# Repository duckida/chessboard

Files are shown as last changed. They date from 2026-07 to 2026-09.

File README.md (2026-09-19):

Screenshot 2026-09-19 at 4 45 12 PM

## what is this?


An electronic chessboard to play against others online, chess engines, or others in person (and get hints)!

Click [here](https://user-cdn.hackclub-assets.com/019f8627-e8d6-7e0b-9ccc-8cd9828df5a0/chessboard%20demo.mp4) for a video demo!

## why did I build it?
I love playing chess, and one of the best ways to improve is with practice against others or a computer. However, this normally requires playing online, which is more distracting. I wanted to build a chessboard where I could play with anyone in the world or with a computer on a traditional board.

## how it works
The chessboard is controlled by a Raspberry Pi (Zero 2 W), which runs the backend API, LEDs, main hardware loop & displays the frontend. 

Reed switches are read by a Raspberry Pi Pico and data is transmitted to the main Pi over UART.

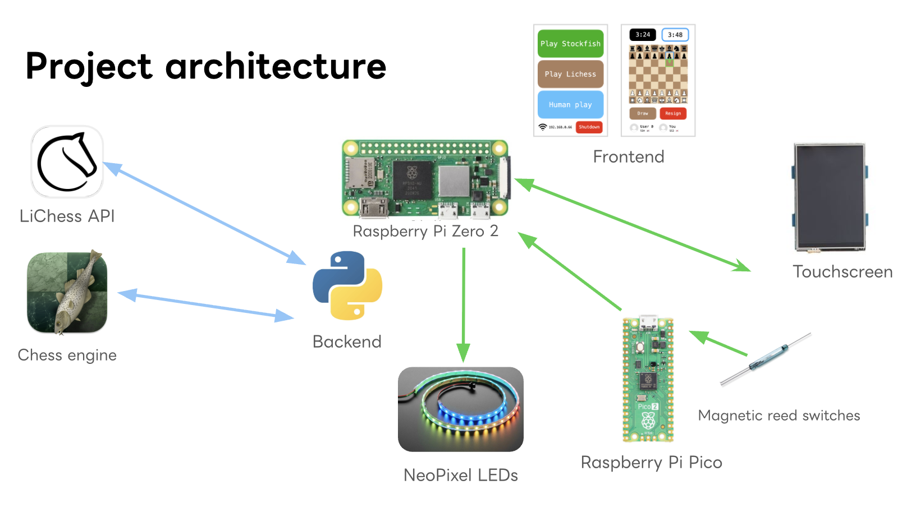
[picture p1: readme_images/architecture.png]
Architecture diagram


## how to set up
Follow the instructions in each folder (backend, frontend, cad and pico_matrix_scan)'s README to deploy each module!

So far, only playing against the chess engine works, with more features coming soon!

A bill of materials can be found in BOM.csv.

## my build journey


Throughout the project, I kept a journal at [JOURNAL.md](https://github.com/duckida/chessboard/blob/main/JOURNAL.md)!

AI usage is also declared in JOURNAL.md.

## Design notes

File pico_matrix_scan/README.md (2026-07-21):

# pico-matrix-scan

This folder contains the code to flash onto a Pico connected to the reed switches.

It reads the matrix of reed switches and outputs to the Pi over Serial (USB).

You only need to copy `main.py` and `keypad_lib.py`.

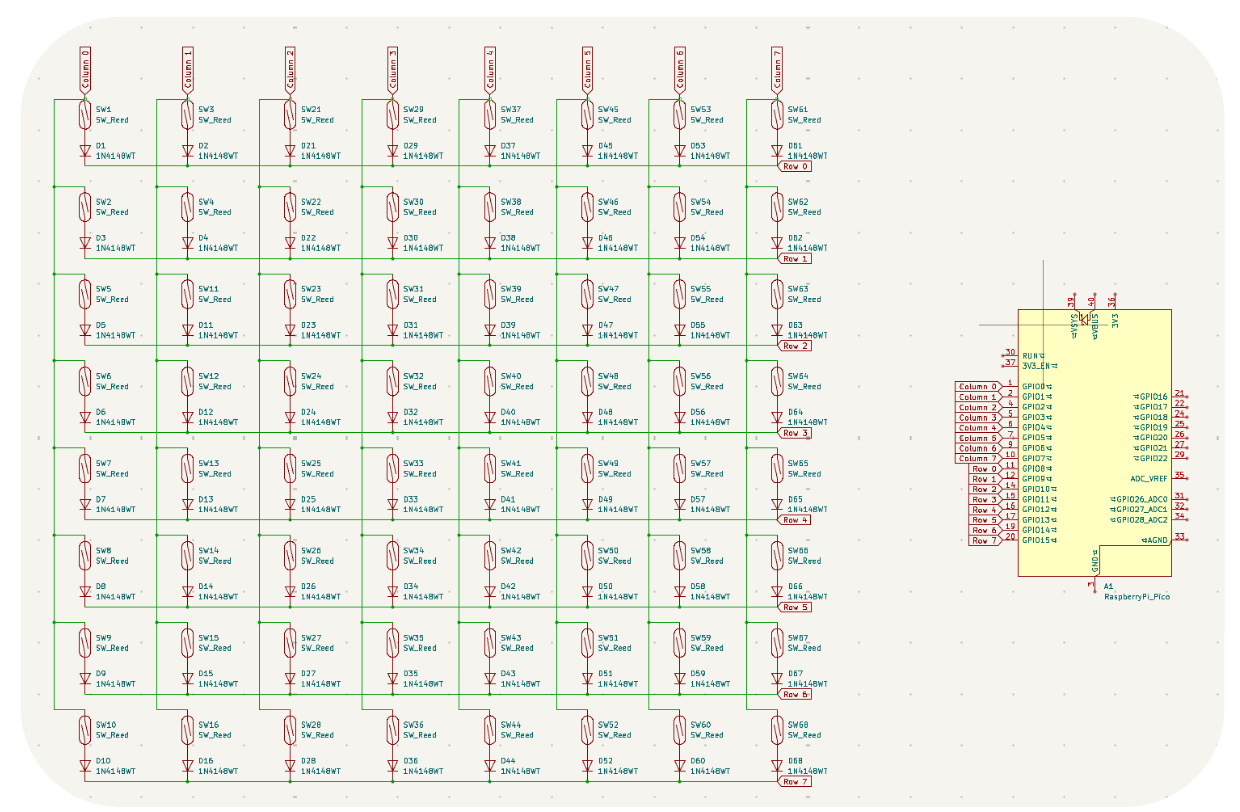
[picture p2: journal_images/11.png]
Full KiCAD schematic


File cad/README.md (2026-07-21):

# cad

This folder contains the CAD designs for the chessboard.

You will need to 3D print all the items in `3d-prints/` - the board has been split into parts so it fits on print beds. 

You will also need to laser cut the base and spacer from `laser-cut/`.

The chessboard was designed in TinkerCAD but has been exported to Fusion 360 .f3d for editing if required.

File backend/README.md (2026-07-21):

# backend

This is the folder that runs on the Raspberry Pi inside the chessboard, communicating with LiChess & the Stockfish chess engine. It also scans hardware inputs and manages the NeoPixel LEDs.

## backend API
The API routes that create and modify games and connect to different services are in `app.py`, which is a Flask API. 

Details about API routes can be found in [API.md](https://github.com/duckida/chessboard/blob/main/backend/API.md).

## hardware interface
The backend folder also contains 2 hardware modules, `leds.py` which exposes a simple control interface for WS2812B strips used in the chessboard (this needs root) and `matrix.py` which reads the matrix over UART serial.

## backend deployment instructions
1. Install uv: `curl -LsSf https://astral.sh/uv/install.sh | sh` and restart your shell
2. Clone this repo and enter: `git clone https://github.com/duckida/chessboard && cd chessboard`
3. Enter the backend and install packages: `cd backend && uv sync`
4. Download Stockfish 14 and compile it, and put this compiled binary at `/home/pi/chessboard/stockfish`
5. Get a LiChess API token and put it in `.env` (example: `LICHESS_TOKEN="lip..."
`)
4. In one terminal tab, run the backend API: `uv run app.py`
5. In another tab, run the hardware scanner / main loop: `sudo -E $(which uv) run main.py` (sudo is needed for LED interfacing and serial reading)

### systemd service - API
1. `sudo systemctl edit --full api.service --force`
2. Paste this in:
```
[Unit]
Description=Chessboard API Service
After=network.target

[Service]
Type=simple
User=pi
WorkingDirectory=/home/pi/chessboard/backend
ExecStart=/home/pi/.local/bin/uv run /home/pi/chessboard/backend/app.py

[Install]
WantedBy=network.target
```
3. `sudo systemctl daemon-reload`
4. `sudo systemctl enable api.service`
5. Reboot the Pi: `sudo reboot`

### systemd service - main hardware loop
> This runs as root, run at your own risk!

1. `sudo systemctl edit --full main.service --force`
2. Paste this in:
```
[Unit]
Description=Chessboard main loop Service
After=network.target api.service 
Wants=api.service

[Service]
Type=simple
User=root
WorkingDirectory=/home/pi/chessboard/backend
ExecStart=/home/pi/.local/bin/uv run /home/pi/chessboard/backend/main.py
Restart=on-failure
RestartSec=3

[Install]
WantedBy=network.target
```
3. `sudo systemctl daemon-reload`
4. `sudo systemctl enable main.service`
5. Reboot the Pi: `sudo reboot`

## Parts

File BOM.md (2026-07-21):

| Component | Link | Quantity |
| --- | --- | --- |
| Raspberry Pi | [Raspberry Pi](https://www.raspberrypi.com/products/raspberry-pi-zero-2-w/) | 1 |
| 16GB microSD card | [CPC](https://cpc.farnell.com/integral/inmsdh16g-100v10/16gb-microsdhc-v10-uhs-i-u1/dp/MD01157) | 1 |
| NeoPixel strip (30 / m) | [Amazon](https://www.amazon.co.uk/BTF-LIGHTING-Individual-Addressable-60Pixels-Non-Waterproof/dp/B088BB8WTZ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) | 3 meters |
| Reed switches | [Amazon](https://www.amazon.co.uk/QitinDasen-MKA-14103-Magnetic-Induction-Normally/dp/B07ZD4JF76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) | 64 |
| RPi Pico | [Raspberry Pi](https://www.raspberrypi.com/products/raspberry-pi-pico/) | 1 |
| Protoboard |  | 265x265mm |
| Diodes | [Amazon](https://www.amazon.co.uk/100PCS-1N4148-IN4148-High-Speed-Switch/dp/B07YZ8G7TG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) | 64 |
| Touchscreen | [Micro Center](https://www.microcenter.com/product/632693/inland-35-inch-tft-lcd-touch-screen-monitor) | 1 |
| Magnetic chess pieces | [Amazon](https://www.amazon.co.uk/gp/product/B086632FYP/ref=ox_sc_act_title_2?smid=A1SD225FBQ4KA&psc=1) | 1 set |

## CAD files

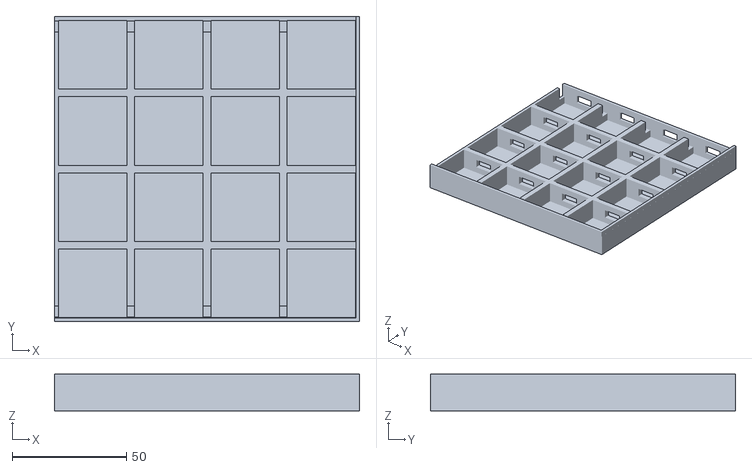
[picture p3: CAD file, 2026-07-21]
cad/3d-prints/chessboard-c.stl
133.2 x 133.2 x 16.0

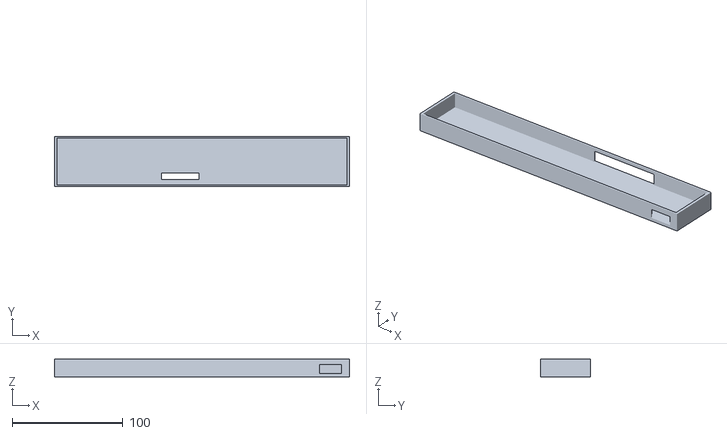
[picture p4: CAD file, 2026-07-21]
cad/3d-prints/chessboard-e.stl
266.4 x 45.0 x 16.0

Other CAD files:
cad/3d-prints/chessboard-a.stl
cad/3d-prints/chessboard-b.stl
cad/3d-prints/chessboard-d.stl
cad/Chessboard.f3d

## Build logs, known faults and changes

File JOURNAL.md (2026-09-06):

# chessboard journal

June 23: Spent 20mins creating a project brief and bill of materials

June 27: Spend 45mins writing a Python program to use `berserk` API to connect to LiChess and learn about the streamed events

July 2: looked for parts online from a variety of resellers

July 4: 
- ordered parts on Amazon
- used threading to make a basic Flask API to search for games
- added make move function
 
July 5: 
- got a basic API working and was able to move pieces against another player with it! 
- Learned the basics of Next.js and started making the frontend

July 6: got basic interaction between the frontend & backend working!

July 7: 
- parts arrived! 
- got a basic code with reed switches to work. 
- Designed a prototype for 4 chessboard squares in TinkerCAD.

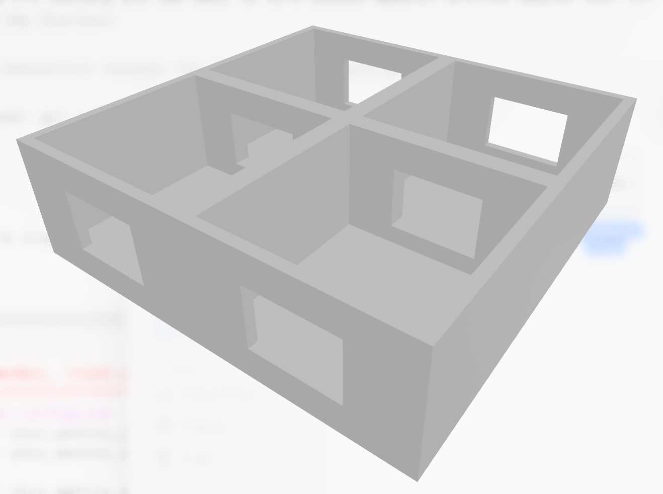
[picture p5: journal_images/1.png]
First TinkerCAD design


- Next, I tested my NeoPixels, and I need to find a way to diffuse them better.

- This design wasn't as good for the reed switch height, so I did another one which was less tall and thinner surface, and tested with 2 squares.

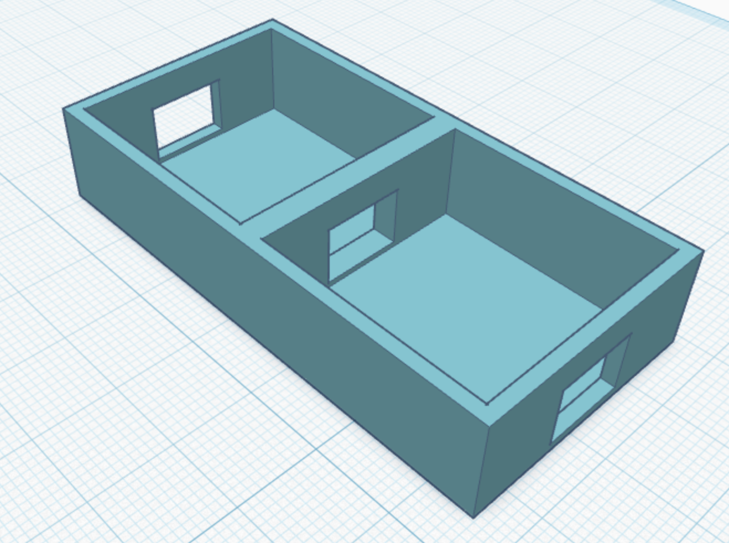
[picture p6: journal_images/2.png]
Improved design


- This also lights up better, and fits the reed switch!

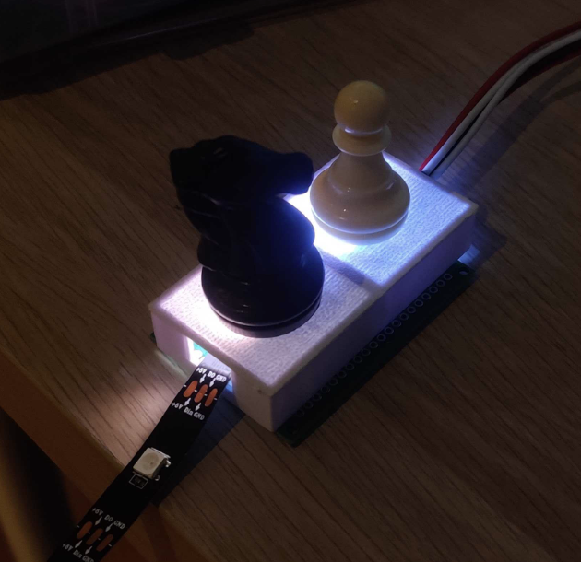
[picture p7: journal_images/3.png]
Printed improved design


July 8: 
- 3D printed a 4-square version of the new design. 
- Drew up a KiCad schematic of the matrix layout!

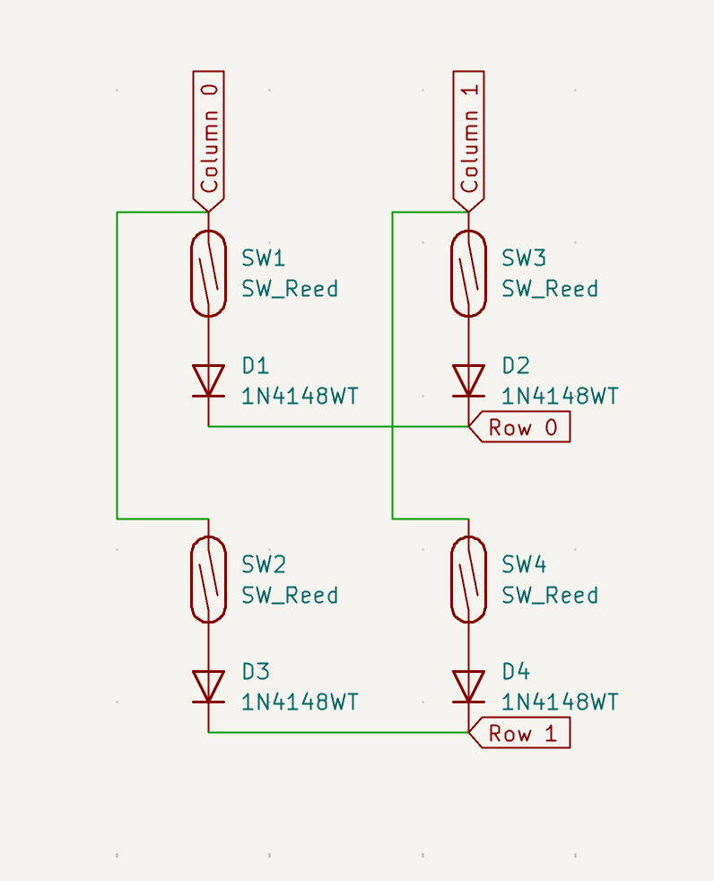
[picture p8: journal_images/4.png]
Matrix schematic


- Soldered the reed switches in a matrix layout
- Got the 2x2 mini board to work!
- Wrote a custom matrix keypad library based on an existing one to output an array which i can use

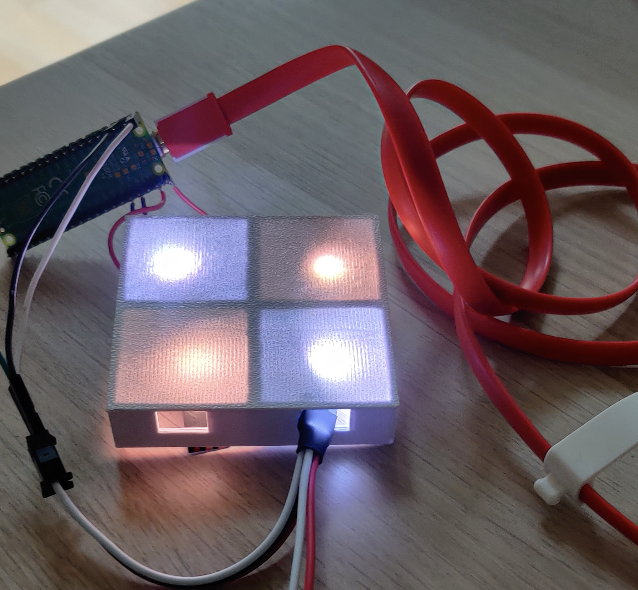
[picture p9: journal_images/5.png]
Working 2x2 mini board


July 9 - Created a home page with Next.js (learned about Tailwind CSS and shadcn/ui)

July 10:
- Fixed a duplicate move issue in the frontend
- Soldered pins to my Raspberry Pi (decided to use a Zero 2W as it's smaller)
- Flashed the SD card for the Pi and configured the OS
- Compiled Stockfish on the Pi
- Got Stockfish best move analysis to show on the frontend!

July 12: Set up the Pi touchscreen & X11

July 13:
- Designed a full-size chessboard in TinkerCAD and added a section for the Pi, screen & Pico (had to split it into multiple pieces to print)
- Printed the end section which stores the Pi, Pico and screen
- Worked on the backend, creating a class for Stockfish game and API routes for it

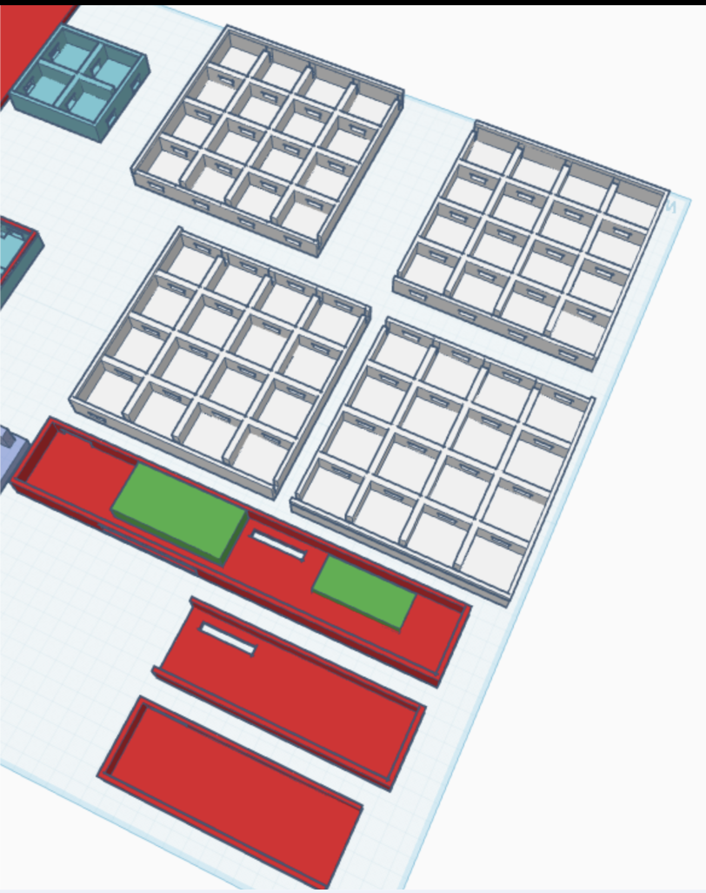
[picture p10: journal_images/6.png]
TinkerCAD design


July 14:
- Printed the chessboard squares
- Soldered the display pins (messed this up so had to redo it) and NeoPixel strip to the Pi
- Tested the NeoPixel strip with the Pi
- Lots of debugging to get the screen to work (messed up pins, framebuffers, and bridging!)
- Software work - added human vs human game routes to the API and integrated them into the frontend
- Compiled the Next.js app
- Designed a KiCAD schematic for the full size matrix

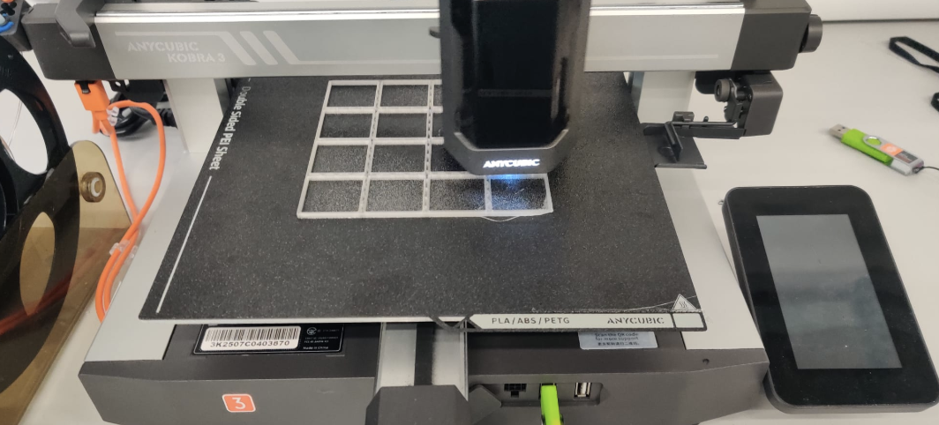
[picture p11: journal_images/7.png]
Printing squares

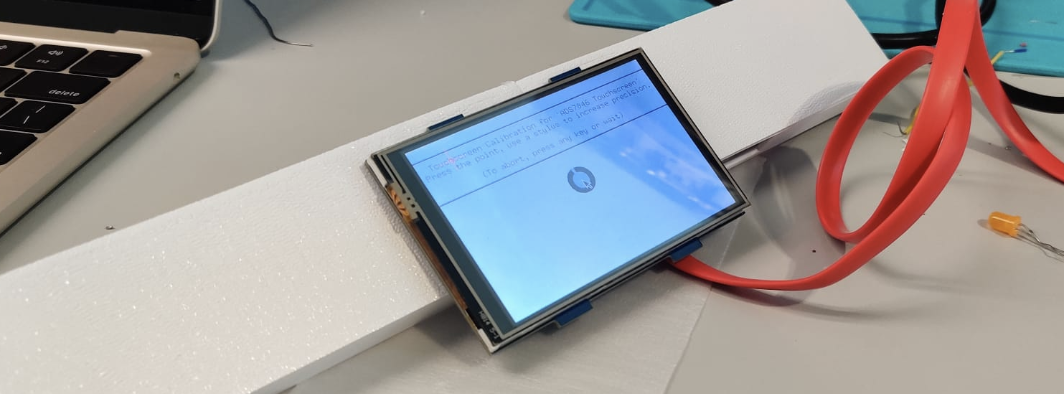
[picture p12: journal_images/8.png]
Display working

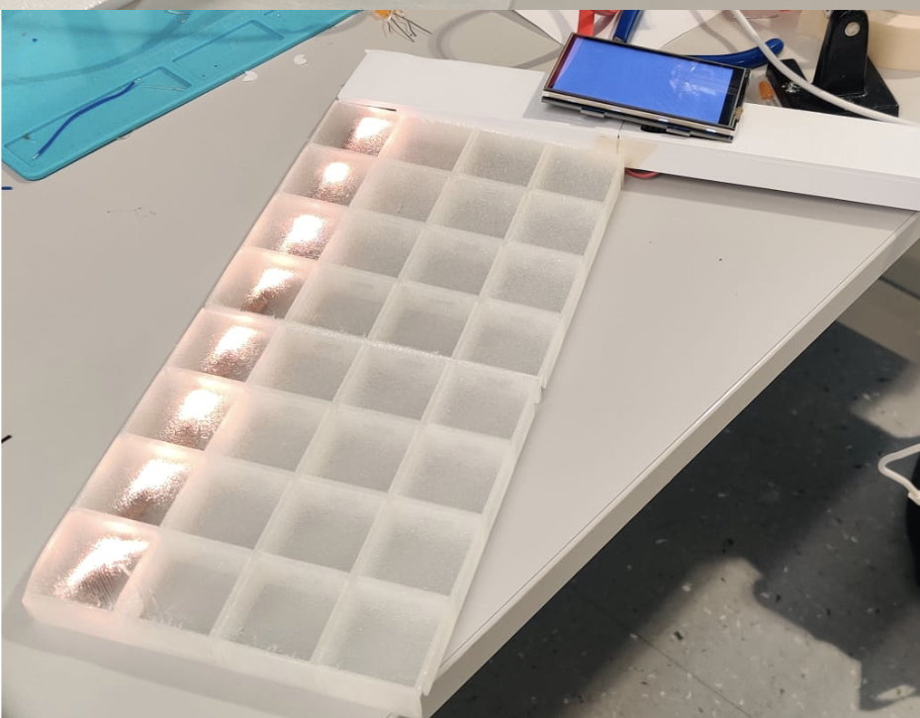
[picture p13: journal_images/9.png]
Tested NeoPixel strip


July 15:
- Used a guillotine to cut the protoboards to size
- Soldered the reed switches to the protoboard
- Soldered wires for the matrix columns

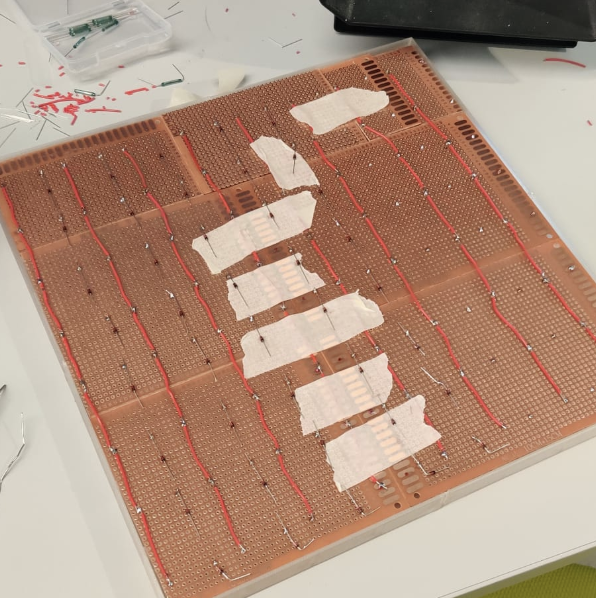
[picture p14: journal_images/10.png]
All the NeoPixels fitting in the board


July 16:
- Soldered all diodes to the matrix
- Soldered row wires
- Added the Pico pinout of rows & columns to my KiCAD schematic
- Soldered the column & rows to the Pico 
- Tested the matrix, many squares didn't work so I had to resolder loose wires etc.

Full KiCAD schematic
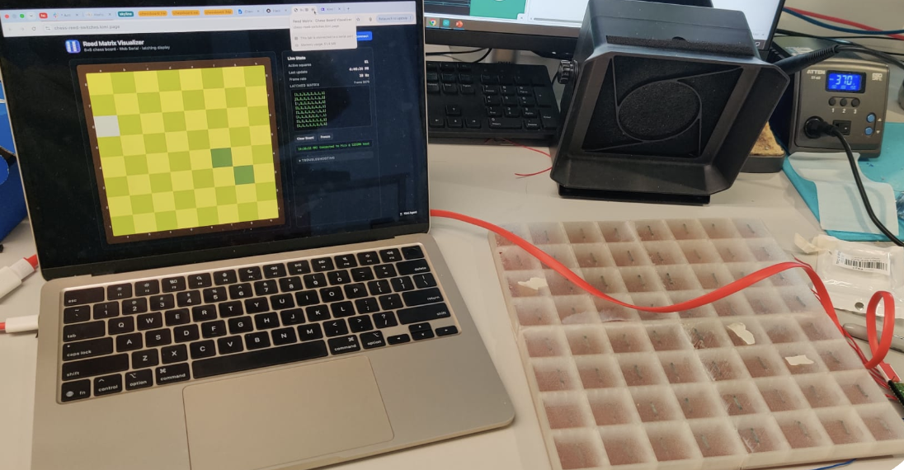
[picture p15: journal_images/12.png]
Testing the reed switches with a vibe-coded webapp


July 17:
- Got all the matrix keys to work after much testing, resoldering and alignment!
- Laser cut a base and base spacer
- Tried to put the NeoPixels in and failed, so made the holes bigger
- Soldered the NeoPixels and put them in through the reed switches
- Started testing the NeoPixels

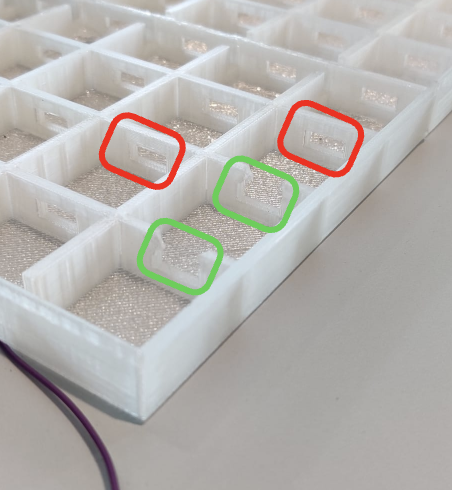
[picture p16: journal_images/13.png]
Holes I had to cut

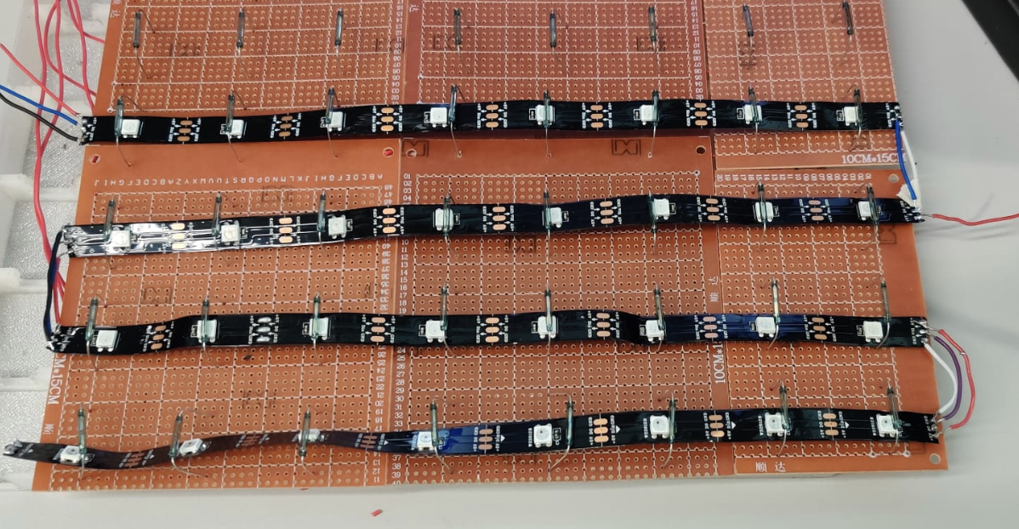
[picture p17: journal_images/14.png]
Soldering NeoPixels


July 18: soldered & fixed some NeoPixels that didn't work

July 19:
- Got all the NeoPixels to work!
- Deployed the frontend to Vercel and ran it `DISPLAY=:0 surf -F https://chessboard-moa.vercel.app/`

July 20:
- Got all the reed switches and NeoPixels to work
- Hot glued the protoboards to the 3D printed chessboard
- Hot glued the screen enclosure to this
- Soldered Pico UART to the Pi
- Wrote READMEs for the frontend & backend
- Put a paper diffuser layer on the top

All the parts in the shell
Top with the diffuser layer

July 21:
- Wrote a basic demo code to play against Stockfish
- Switched to Stockfish 14 to minimize resource use
- Updated the LED matrix to square mapping
- Got up and down events to work with the reed switches
- Wrote README for the project and backend

Then - Sep 6:
- Used AI to create a main.py (i aim to rewrite this by hand after creating the unified API) that links the physical board with the backend
- Added undo API route to Stockfish and an undo button to the UI
- Cleaned up the UI and got it to fit on the screen
- Got the human-vs-human mode to work, and added hint & undo modes
- Added player information route and UI to the LiChess screen
- Started work on a unified API to make interfacing easier between modes

### AI usage
AI helped me with:
- understanding the LiChess API and its responses
- choosing parts to order (comparing datasheets)
- learning Next.js
- help me setup the Pi desktop and framebuffer
- Exporting the Next.js site as static HTML
- Creating a UI to test reed switches (not shipped in the final code)
- Using UART hardware Serial on the Pico and reading this on the Pi
- Fixing systemd service order
- General debugging
- The current `main.py` is written by AI, but this is after shipping to Hack Club. I aim to rewrite this completely myself in the future.

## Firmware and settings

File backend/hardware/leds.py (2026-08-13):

from rpi_ws281x import PixelStrip, Color, ws
import time

class LEDStrip:
    PIXEL_SQUARE_MAPPING = {
        "a1": 56, "a2": 55, "a3": 40, "a4": 39, "a5": 24, "a6": 23, "a7": 8,  "a8": 7,
        "b1": 57, "b2": 54, "b3": 41, "b4": 38, "b5": 25, "b6": 22, "b7": 9,  "b8": 6,
        "c1": 58, "c2": 53, "c3": 42, "c4": 37, "c5": 26, "c6": 21, "c7": 10, "c8": 5,
        "d1": 59, "d2": 52, "d3": 43, "d4": 36, "d5": 27, "d6": 20, "d7": 11, "d8": 4,
        "e1": 60, "e2": 51, "e3": 44, "e4": 35, "e5": 28, "e6": 19, "e7": 12, "e8": 3,
        "f1": 61, "f2": 50, "f3": 45, "f4": 34, "f5": 29, "f6": 18, "f7": 13, "f8": 2,
        "g1": 62, "g2": 49, "g3": 46, "g4": 33, "g5": 30, "g6": 17, "g7": 14, "g8": 1,
        "h1": 63, "h2": 48, "h3": 47, "h4": 32, "h5": 31, "h6": 16, "h7": 15, "h8": 0,
    }

    LED_COUNT = 64
    LED_GPIO = 19
    LED_FREQ = 800000
    LED_DMA = 10
    LED_INVERT = False

    def __init__(self, brightness):
        self.brightness = brightness
        self.strip = PixelStrip(self.LED_COUNT, self.LED_GPIO, self.LED_FREQ, self.LED_DMA, self.LED_INVERT, brightness, channel=1, strip_type=ws.WS2811_STRIP_GRB)
        self.strip.begin()

    def set_square_rgb(self, square, rgb):
        pixel_num = self.PIXEL_SQUARE_MAPPING[square]
        self.strip.setPixelColor(pixel_num, Color(*rgb))

    def set_all_rgb(self, rgb):
        for pixel in range(self.LED_COUNT):
            self.strip.setPixelColor(pixel, Color(*rgb))

    def set_matrix_rgb(self, rgb_white, rgb_black):
        for pixel in range(1, self.LED_COUNT, 2):
            self.strip.setPixelColor(pixel, Color(*rgb_white))

        for pixel in range(0, self.LED_COUNT, 2):
            self.strip.setPixelColor(pixel, Color(*rgb_black))

    def update(self):
        self.strip.show()

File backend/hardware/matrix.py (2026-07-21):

# Simple serial reading object
# Reads the serial and outputs it as a list

import serial
import json

class ChessboardMatrix:
    def __init__(self):
        self.ser = serial.Serial('/dev/serial0', 115200, timeout=1)

    def get_state(self):
        # Throw away any backlog we only want the freshest reading
        self.ser.reset_input_buffer()

        while True:
            try:
                raw_bytes = self.ser.readline()
                matrix_string = raw_bytes.decode("utf-8", errors="ignore").strip()
                if not matrix_string:
                    continue
                matrix = json.loads(matrix_string)
                return matrix
            except (UnicodeDecodeError, json.JSONDecodeError):
                continue

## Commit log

2026-07-05 fix timedelta issue, add API doc
    [main.py]
2026-07-07 add pico matrix scanning test
2026-07-07 update journal with new design print
2026-07-08 update journal, add schematic
2026-07-08 add schematic image
2026-07-08 update matrix scan
    [pico_matrix_scan.kicad_sch]
2026-07-09 add home page with buttons
2026-07-09 rename play_lichess, add links to buttons
2026-07-09 make lichess link with frontend board
2026-07-10 Use smaller stockfish model to prevent oom
    [main.py]
2026-07-13 Switch to python-chess api instead of stockfish
2026-07-14 Create full-size schematic
    [pico_matrix_scan.kicad_sch]
2026-07-16 Add Pico to KiCAD schematic
    [pico_matrix_scan.kicad_sch]
2026-07-19 Add LED control
2026-07-20 Switch to hardware UART
2026-07-21 Fix move push to board error
2026-07-21 print ai move
2026-07-21 fix leds
2026-07-21 update led mappings
2026-07-21 update led matrix command
2026-07-21 fix led positional arguments
    [main.py]
2026-07-21 fix matrix reading bugs
    [main.py, matrix.py]
2026-07-21 update led mapping
2026-07-21 call api to reset game
    [main.py]
2026-07-21 Add CAD files
    [Chessboard.f3d, chessboard-a.stl, chessboard-b.stl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]
2026-07-21 Add bill of materials
2026-08-12 swap led colors
2026-08-13 update led direction
2026-08-13 fix led rotation again!
    [leds.py]
2026-08-13 correctly fix the config
    [leds.py, main.py]
2026-08-16 position buttons in column at correct width
2026-08-16 update homepage layout and add back buttons
2026-08-27 update button styles
2026-08-27 make back button reset the game before leaving
2026-08-27 add shutdown button functionality
2026-08-27 (ai) fix some issues in main loop
    [main.py]
2026-08-27 increase text sizes & format lichess buttons
2026-09-01 add human vs human hint button and undo
2026-09-01 update button responsiveness (ai)
2026-09-01 (ai) fix hvh undos
    [main.py]
